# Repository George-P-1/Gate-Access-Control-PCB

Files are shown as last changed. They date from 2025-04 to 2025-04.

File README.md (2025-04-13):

# Gate Access Control - PCB Design

A custom-designed PCB for a smart gate access control system, created using KiCad. It features both programming and power management components intended as part of a smart automation system for gates. This project was done as part of a university group assignment.

The system allows access via RF remote, switch or RFID tag and includes safety mechanisms like human detection inputs (photo sensors) that prevent gate operation. The board is designed to be AC-powered, with an onboard AC-DC converter and expansion-ready via various screw terminals and headers.

---

## Project Overview

This project involved designing a custom PCB using **KiCad 7**, building the schematic and layout, selecting components and producing a bill of materials. 

## Project Concept

> “Make a device that authenticates the opening of a gate using a remote, switch or RFID tag and opens the gate using a motor drive - unless two photo sensors detect a person near the gate.”

**System Requirements:**
- Input options: RF remote, switch, RFID
- Output: Control signals to motor/inverter (speed + direction)
- Safety: If two photo sensor inputs detect a person, do not open gate; flash warning lights instead
- Power: Must be powered by **AC mains** using an onboard **AC-DC converter**
- Controller: Custom implementation using **ATmega328 (from Arduino Uno R3)**

**Safety Considerations:**

- **AC spacing**: >6.35mm between live and neutral traces to prevent arcing
- **Creepage distance** maintained around J1 (power input)
- **Fuse** to limit overcurrent from AC-DC converter
- **Trace width** increased for AC paths

---

## PCB and Schematic Preview

### Schematic
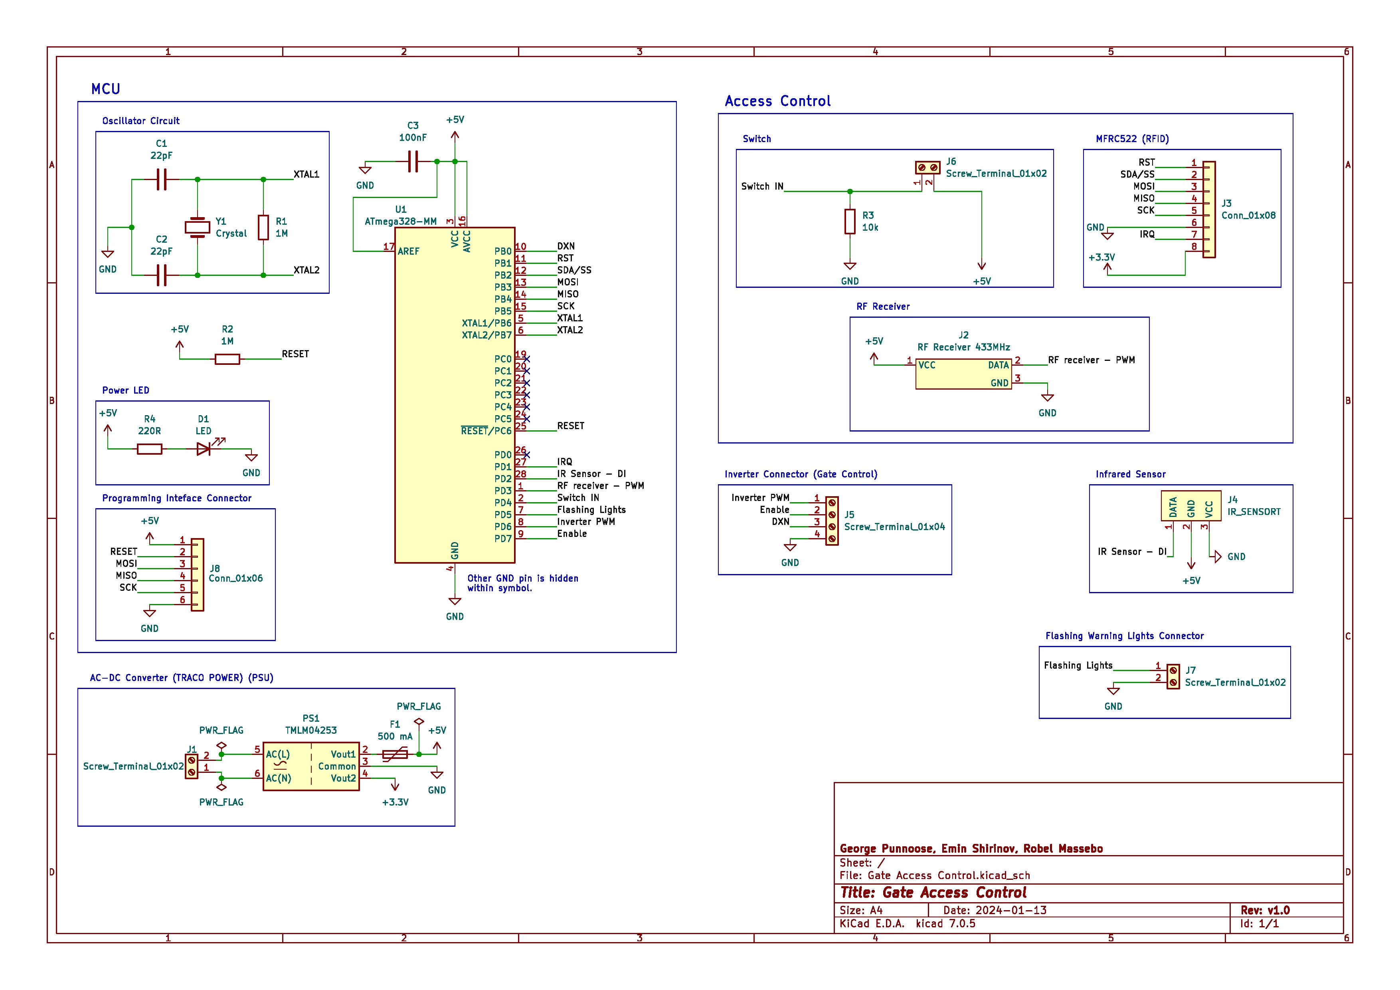
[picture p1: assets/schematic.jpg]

See pdf [here](./docs/Printable%20Schematic%20-%20Gate%20Access%20Control.pdf) for a detailed view.

### PCB Layout
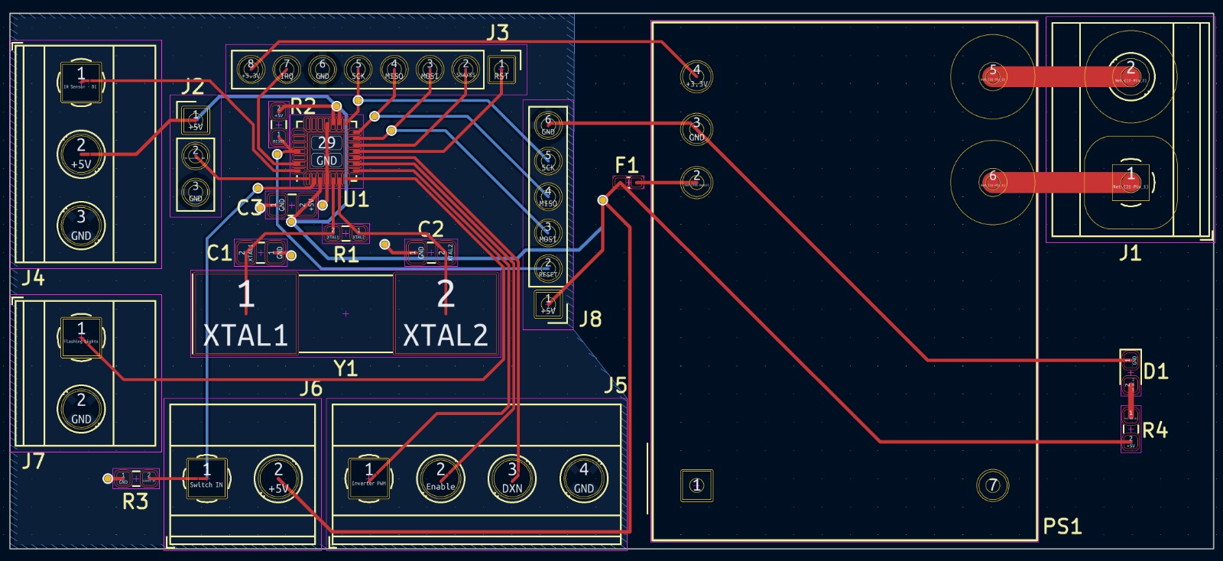
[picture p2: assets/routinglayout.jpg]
PCB Layout
 

### 3D View
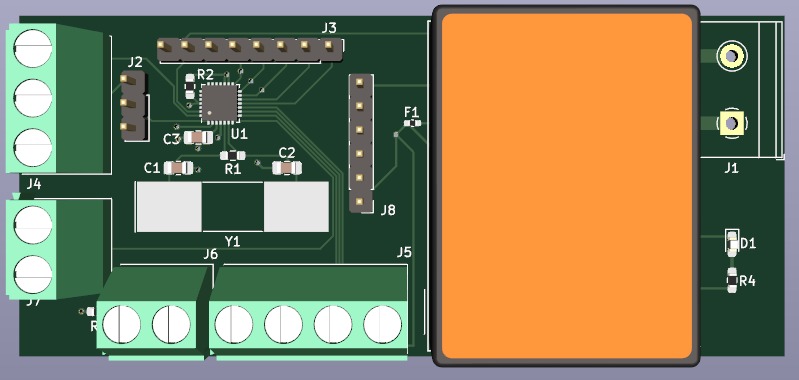
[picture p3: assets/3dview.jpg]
3D PCB View


---

## 🧾 Bill of Materials (BOM)

> For detailed pricing and sourcing: [See BOM PDF](<./docs/BOM (Gate Access Control).pdf>)

[Download CAM Files (Gerbers + Drill Maps)](<./docs/CAM Files - Gerber and Drill Maps.zip>)  
These were used to estimate PCB production cost and can be uploaded to fabrication services (such as PCBway).

## Tools Used

- **KiCad 7** – Schematic and PCB design
- **Mouser** – Component sourcing
- **GitHub** – Project version control and documentation

## Team

- [George Punnoose](https://www.github.com/George-P-1) (Lead)
- [Emin Shirinov](https://github.com/Codeexia0)
- [Robel Massebo](https://www.github.com/RobelKa)

This project was developed for academic purposes and may require adaptation for industrial or commercial deployment.

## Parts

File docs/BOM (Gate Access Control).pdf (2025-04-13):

Source: | ...\Gata Access Control\Gate Access Control.kicad_sch
Date: | 14/01/2024
Component Count: | 20
1 | C1, C2 | 2 | 22pF | C | Capacitor_SMD:C_0805_2012Metric_Pad1.18x1.45mm_HandSolder | Unpolarized capacitor | Mouser.pl | 0.935 zl | 0.612 zl | 0.315 zl | 1.87 zl | 12.24 zl | 63.00 zl | https://www.mouser.pl/ProductDetail/KYOCERA-AVX/0805YA220JAT2A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
2 | C3 | 1 | 100nF | C | Capacitor_SMD:C_0805_2012Metric_Pad1.18x1.45mm_HandSolder | Unpolarized capacitor | Mouser.pl | 0.773 zl | 0.511 zl | 0.258 zl | 0.77 zl | 5.11 zl | 25.80 zl | https://www.mouser.pl/ProductDetail/KYOCERA-AVX/08055C104J4T2A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
3 | D1 | 1 | LED | LED | LED_SMD:LED_0603_1608Metric_Pad1.05x0.95mm_HandSolder | Light emitting diode | Mouser.pl | 1.940 zl | 1.210 zl | 0.699 zl | 1.94 zl | 12.10 zl | 69.90 zl | https://www.mouser.pl/ProductDetail/Broadcom-Avago/ASCKCW01-NW3X3F1H302?qs=OcgtsXO%252B3gtJzS8HV1a3Bw%3D%3D
4 | F1 | 1 | 500 mA | Polyfuse | Fuse:Fuse_0603_1608Metric_Pad1.05x0.95mm_HandSolder | Resettable fuse, polymeric positive temperature coefficient | Mouser.pl | 0.730 zl | 0.621 zl | 0.511 zl | 0.73 zl | 6.21 zl | 51.10 zl | https://www.mouser.pl/ProductDetail/Bussmann-Eaton/PTS06039V020?qs=aP1CjGhiNiFHaAU1CYpiWQ%3D%3D
5 | J1 | 1 | Screw_Terminal_01x02 | Screw_Terminal_01x02 | TerminalBlock_MetzConnect:TerminalBlock_MetzConnect_Type175_RT02702HBLC_1x02_P7.50mm_Horizontal Generic screw terminal, single row, 01x02, script generated (kicad-library-utils/schlib/autogen/connector/) Mouser.pl | 10.230 zl | 10.230 zl | 8.570 zl | 10.23 zl | 102.30 zl | 857.00 zl | https://www.mouser.pl/ProductDetail/Phoenix-Contact/1731022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
6 | J2 | 1 | RF Receiver 433MHz | RF_Receiver_433 | Connector_PinHeader_2.54mm:PinHeader_1x03_P2.54mm_Vertical | Pin Header | Mouser.pl | 4.100 zl | 3.340 zl | 3.010 zl | 4.10 zl | 33.40 zl | 301.00 zl | https://www.mouser.pl/ProductDetail/Molex/90120-0763?qs=BLN8Q0P37WbEQIErCRrCtQ%3D%3D
7 | J3 | 1 | Conn_01x08 | Conn_01x08 | Connector_PinHeader_2.54mm:PinHeader_1x08_P2.54mm_Vertical | Generic connector, single row, 01x08, script generated (kicad-library-utils/schlib/autogen/connector/) Mouser.pl | 2.840 zl | 2.370 zl | 2.200 zl | 2.84 zl | 23.70 zl | 220.00 zl | https://www.mouser.pl/ProductDetail/Molex/90120-0128?qs=sGAEpiMZZMvlX3nhDDO4AImA0rOnEZc5zC8hpwicJqQ%3D
8 | J4 | 1 | IR_SENSORT | IR_SENSOR | TerminalBlock_Phoenix:TerminalBlock_Phoenix_MKDS-1,5-3-5.08_1x03_P5.08mm_Horizontal Screw Terminal | Mouser.pl | 5.420 zl | 3.260 zl | 2.880 zl | 5.42 zl | 32.60 zl | 288.00 zl | https://www.mouser.pl/ProductDetail/Weidmuller/1716090000?qs=BTG2th8YmhRwtiTHzuCKAQ%3D%3D
9 | J5 | 1 | Screw_Terminal_01x04 | Screw_Terminal_01x04 | TerminalBlock_Phoenix:TerminalBlock_Phoenix_MKDS-1,5-4-5.08_1x04_P5.08mm_Horizontal Generic screw terminal, single row, 01x04, script generated (kicad-library-utils/schlib/autogen/connector/) Mouser.pl | 9.570 zl | 9.220 zl | 8.220 zl | 9.57 zl | 92.20 zl | 822.00 zl | https://www.mouser.pl/ProductDetail/Phoenix-Contact/1888700?qs=uD%2FdkN7XIa178%2FYTgCWHbg%3D%3D
10 | J6, J7 | 2 | Screw_Terminal_01x02 | Screw_Terminal_01x02 | TerminalBlock_Phoenix:TerminalBlock_Phoenix_MKDS-1,5-2-5.08_1x02_P5.08mm_Horizontal Generic screw terminal, single row, 01x02, script generated (kicad-library-utils/schlib/autogen/connector/) Mouser.pl | 4.850 zl | 4.500 zl | 4.000 zl | 9.70 zl | 90.00 zl | 800.00 zl | https://www.mouser.pl/ProductDetail/Phoenix-Contact/1729128?qs=GFUSqQMLmmnCBVBY3dts9w%3D%3D
11 | J8 | 1 | Conn_01x06 | Conn_01x06 | Connector_PinHeader_2.54mm:PinHeader_1x06_P2.54mm_Vertical | Generic connector, single row, 01x06, script generated (kicad-library-utils/schlib/autogen/connector/) Mouser.pl | 7.250 zl | 6.120 zl | 5.070 zl | 7.25 zl | 61.20 zl | 507.00 zl | https://www.mouser.pl/ProductDetail/Molex/90120-0766?qs=PvP5v7EimskFcAmG4v%252BboQ%3D%3D
12 | PS1 | 1 | TMLM04253 | TMLM04253 | Converter_ACDC:Converter_ACDC_TRACO_TMLM-04_THT | 5V 600mA / 3.3V 150mA AC/DC dual output, low noise power module Moser.pl | 86.950 zl | 81.900 zl | 74.220 zl | 86.95 zl | 819.00 zl | 7,422.00 zl | https://www.mouser.pl/ProductDetail/TRACO-Power/TMLM-04253?qs=ckJk83FOD0Wmhe7uo3J7yw%3D%3D
13 | R1, R2 | 2 | 1M | R | Resistor_SMD:R_0603_1608Metric_Pad0.98x0.95mm_HandSolder | Resistor | Mouser.pl | 2.410 zl | 1.140 zl | 0.898 zl | 4.82 zl | 22.80 zl | 179.60 zl | https://www.mouser.pl/ProductDetail/Vishay-Beyschlag/MCT0603MD1004BP500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
14 | R3 | 1 | 10k | R | Resistor_SMD:R_0603_1608Metric_Pad0.98x0.95mm_HandSolder | Resistor | Mouser.pl | 0.431 zl | 0.037 zl | 0.023 zl | 0.43 zl | 0.37 zl | 2.30 zl | https://www.mouser.pl/ProductDetail/Bourns/CR0603-FX-1002ELF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
15 | R4 | 1 | 220R | R | Resistor_SMD:R_0603_1608Metric_Pad0.98x0.95mm_HandSolder | Resistor | Mouser.pl | 1.160 zl | 0.532 zl | 0.241 zl | 1.16 zl | 5.32 zl | 24.10 zl | https://www.mouser.pl/ProductDetail/Panasonic/ERA-3AED221V?qs=sGAEpiMZZMtlubZbdhIBINE5Vwz7C5t%2Fw4SSsxCA25U%3D
16 | U1 | 1 | ATmega328-MM | ATmega328-MM | Package_DFN_QFN:QFN-28-1EP_4x4mm_P0.45mm_EP2.4x2.4mm | 20MHz, 32kB Flash, 2kB SRAM, 1kB EEPROM, QFN-28 | Mouser.pl | 10.930 zl | 10.930 zl | 9.070 zl | 10.93 zl | 109.30 zl | 907.00 zl | https://www.mouser.pl/ProductDetail/Microchip-Technology/ATMEGA328-MMH?qs=950R68cwx9ewrNKehJkItw%3D%3D
17 | Y1 | 1 | Crystal | Crystal | Crystal:Crystal_SMD_Abracon_ABM3-2Pin_5.0x3.2mm | Two pin crystal, 16MHz | Mouser.pl | 2.280 zl | 1.700 zl | 1.510 zl | 2.28 zl | 17.00 zl | 151.00 zl | https://www.mouser.pl/ProductDetail/ABRACON/ABM3-16.000MHZ-D2Y-T?qs=ihRgKfnEsN66T7SnvB1%2FxQ%3D%3D

Note: Component cost may change slightly.

Component Cost | PCB Cost
S.I. No. | Reference | Quantity | Value | Component Name | Footprint | Description | Vendor | Unit Cost (1 szt) | Unit Cost (10 szt) | Unit Cost (100 szt) | Cost (1 PCB) | Cost (10 PCB) | Cost (100 PCB) | Link
| 1 PCB | 10 PCB | 100 PCB
Total | Unit Cost | Total | Unit Cost | Total | Unit Cost
Total Component Cost: PCB Production Cost: SUM: | 160.99 zl | 160.99 zl 17.320 zl 178.31 zl | 1,444.85 zl | 144.49 zl 3.211 zl 147.70 zl | 12,690.80 zl | 126.91 zl 2.247 zl 129.15 zl
| 17.32 zl | | 32.11 zl | | 224.67 zl
| 178.31 zl | | 1,476.96 zl | | 12,915.47 zl

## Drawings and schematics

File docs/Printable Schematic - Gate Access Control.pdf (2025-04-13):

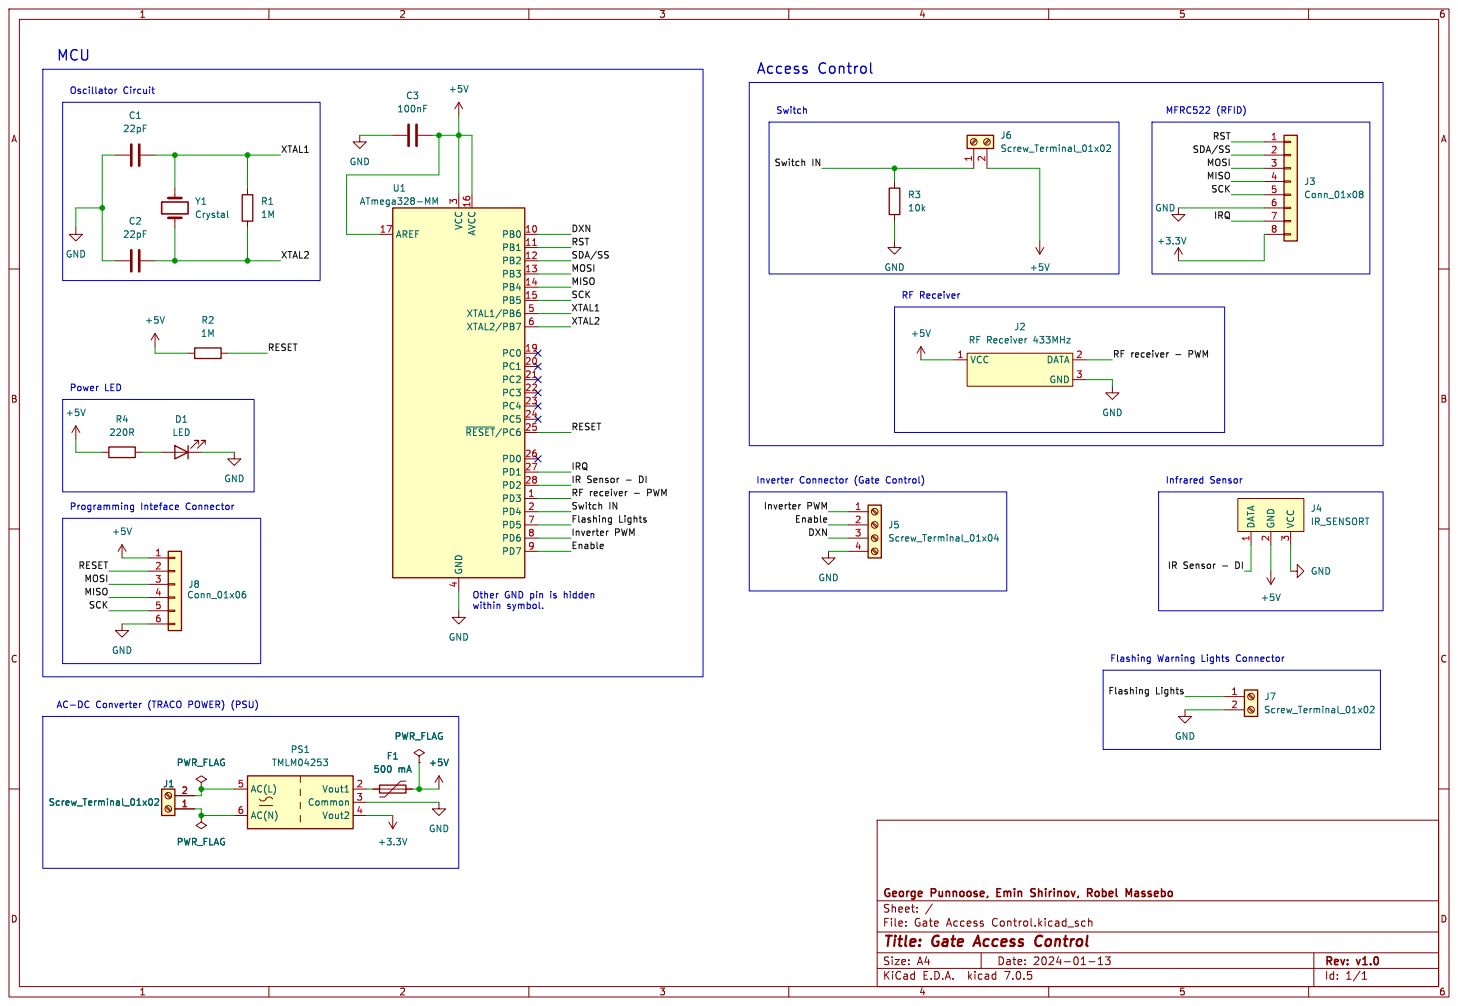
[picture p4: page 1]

Flashing Warning Lights Connector RF Receiver Other GND pin is hidden within symbol. Power LED

AC-DC Converter (TRACO POWER) (PSU)

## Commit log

2023-11-30 Added Switch and Inverter Connections (#8)
    [Gate Access Control.kicad_sch]
2023-12-02 Neater Schematic
    Made sheet back to A4 size, renamed some of the titles of rectangles and moved around the rectangles.
    [Gate Access Control.kicad_sch]
2023-12-03 Added Footprints for all Connectors and Resistors
    Footprints for ATmega328 and AC-DC converter were already selected by KiCAD and I double checked with datasheet.
    Footprints for connectors J1 to J5 and resistors R1 to R3 were added.
    Edited value of resistor R3 and text about GND pins of ATmega328.
    [Gate Access Control.kicad_sch]
2023-12-07 Modified Connectors' Symbols and Footprints, And Resistor and Crystal Footprints
    Replaced switch with a Screw Terminal
    [Gate Access Control.kicad_sch]
2023-12-08 Added fuse and footprints for capacitors
    Added fuse after ac-dc converter for safety and assigned its tripping value as 200mA and added footprints for capacitors and fuse.
    [Gate Access Control.kicad_sch]
2023-12-08 Added Programming Interface and Flashing Warning Lights Connectors
    Added symbols and footprints for them
    [Gate Access Control.kicad_sch]
2023-12-09 Changed ATmega328 from DIP to SMD (QFN)
    Footprint was automatically changed.
    DIP-28 to QFN-28
    [Gate Access Control.kicad_sch]
2023-12-09 Added Power LED
    Added corresponding footprints also.
    Also corrected a label name of Programming Interface Connector.
    [Gate Access Control.kicad_sch]
2023-12-09 Changed Symbol of the Flashing Lights Connector
    Screw Terminal to Generic Connector
    [Gate Access Control.kicad_sch]
2023-12-12 Added Ground pins for external connection
    Ground pins for reference for outside circuits
    [Gate Access Control.kicad_sch]
2023-12-13 Connected the IRQ pin of RFID connector to ATmega328
    Using D1 (TX) pin for the IRQ (Interrupt) connection since UART communication is not being used.
    [Gate Access Control.kicad_sch]
2023-12-20 Corrected Symbol and Footprint of 2 Connectors
    Footprints and Symbols of Programming Interface Connector and Flashing Warning Lights Connector were switched.
    [Gate Access Control.kicad_sch]
2024-01-05 Merge for Selected and Finalized PCB Design (#11)
    * Configured Physical Stackup, Board Editor Layers & Design Rules
    * Placed Component Blocks and Arranged Component Blocks in PCB
    * Routed All Traces
    Added Ground Plane.
    * Changed Symbol and footprint of RF Receiver
    RF Receiver had one unnecessary unconnected pin.
    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
    [Gate Access Control.kicad_pcb, Gate Access Control.kicad_sch]
2024-01-08 Assigned Smaller Footprint for Crystal
    Also changed fuse value and footprint.
    [Gate Access Control.kicad_pcb, Gate Access Control.kicad_sch]
2024-01-13 Even Smaller Crystal Footprint and added Labels for External Connections
    Also Beautified Schematic Layout
    [Gate Access Control.kicad_pcb, Gate Access Control.kicad_sch]
2025-04-13 Added readme and other relevant files related to this project
    [Gate Access Control BOM.xlsx]
